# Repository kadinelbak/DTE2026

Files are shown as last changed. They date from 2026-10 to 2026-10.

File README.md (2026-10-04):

# DTE 2026

Hardware for the DTE Designathon project.

## EMG + Stretch Sensor Board

KiCad 8 project in [`hardware/emg_board/`](hardware/emg_board/). Open `emg_board.kicad_pro` in KiCad; the symbol and footprint libraries are project-local, so nothing needs to be installed.

```
hardware/emg_board/
├── emg_board.kicad_pro     project
├── emg_board.kicad_sch     schematic
├── emg_board.kicad_pcb     PCB layout
├── EMG_Board.kicad_sym     project symbol library
├── EMG_Board.pretty/       project footprint library (*.kicad_mod)
├── sym-lib-table           points to ${KIPRJMOD}/EMG_Board.kicad_sym
├── fp-lib-table            points to ${KIPRJMOD}/EMG_Board.pretty
└── docs/                   schematic and PCB previews and screenshots
```

The board runs from a 9 V battery through a switch, a reverse-polarity diode and a 7805 regulator into an ESP32 DevKit (38-pin). It carries:

- an EMG front end (instrumentation amp, 8 Hz high-pass, ~800 Hz low-pass, total gain ~1200) on IO34
- a Wheatstone bridge for two stretch sensors on IO35 / IO33
- a potentiometer on IO32
- three indicator LEDs on IO25 / IO26 / IO27

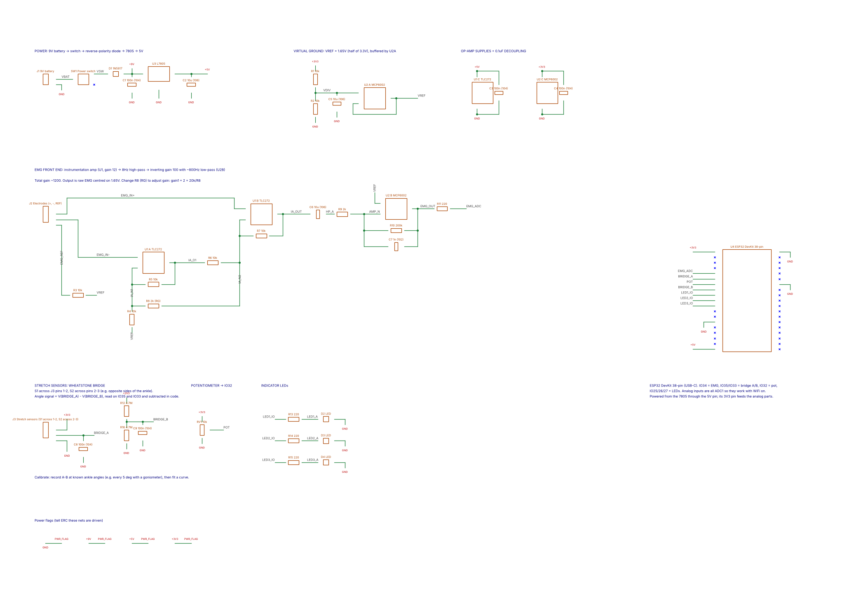
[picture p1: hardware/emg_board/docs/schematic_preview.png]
Schematic

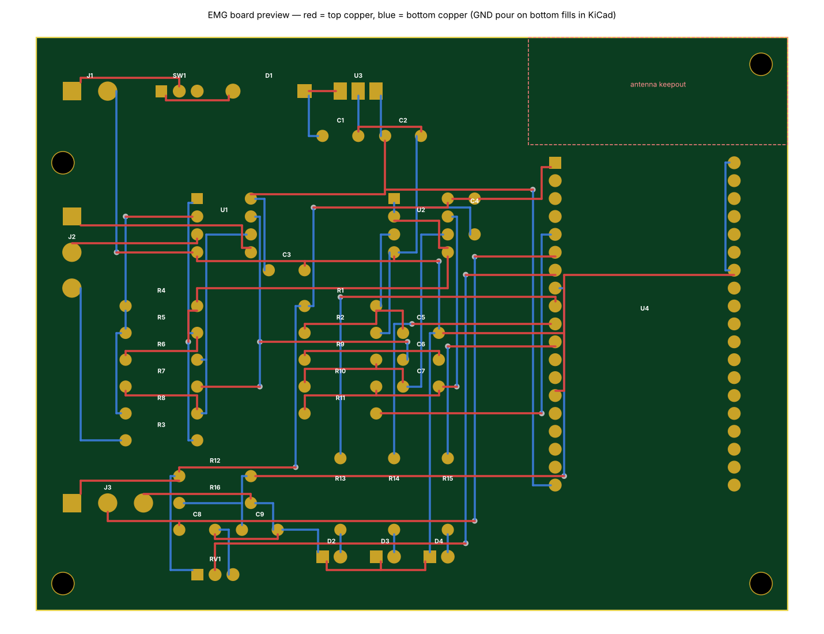
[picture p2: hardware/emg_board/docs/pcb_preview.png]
PCB


### KiCad screenshots

PCB layout:

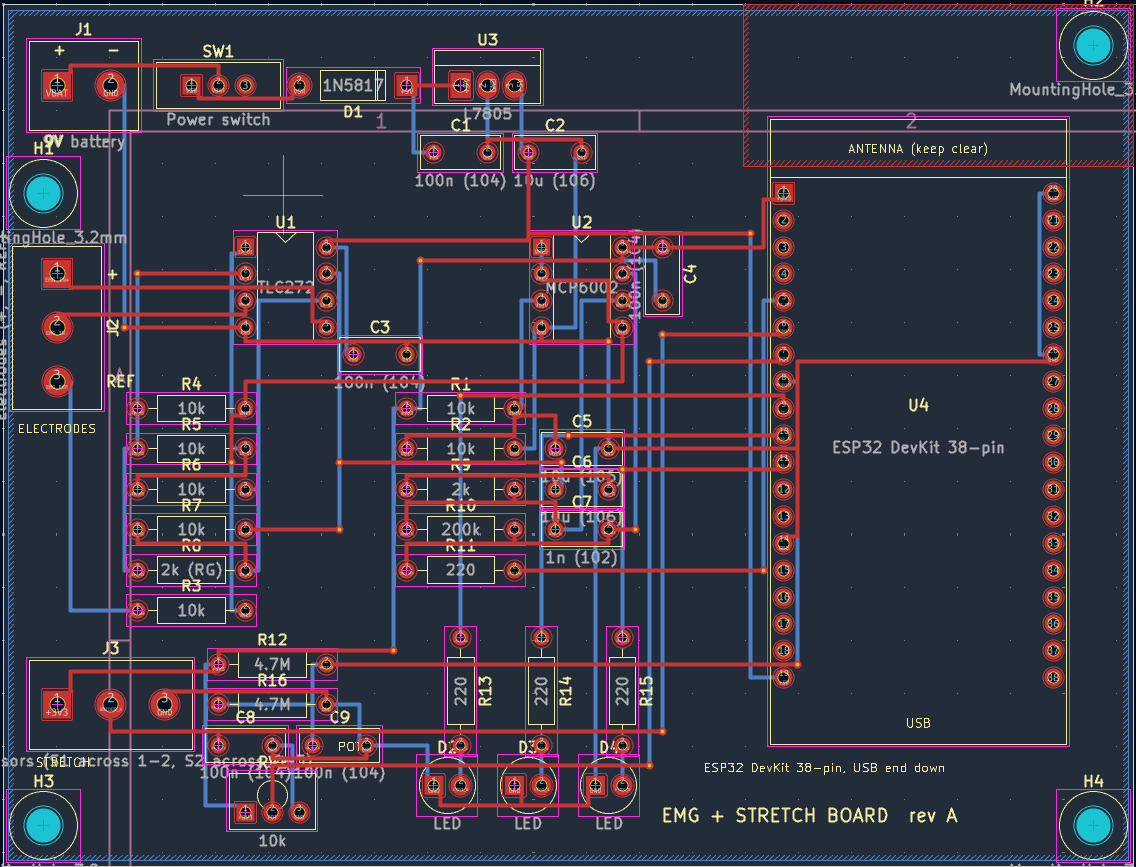
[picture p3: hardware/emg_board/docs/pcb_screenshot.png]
PCB layout in KiCad


Schematic:

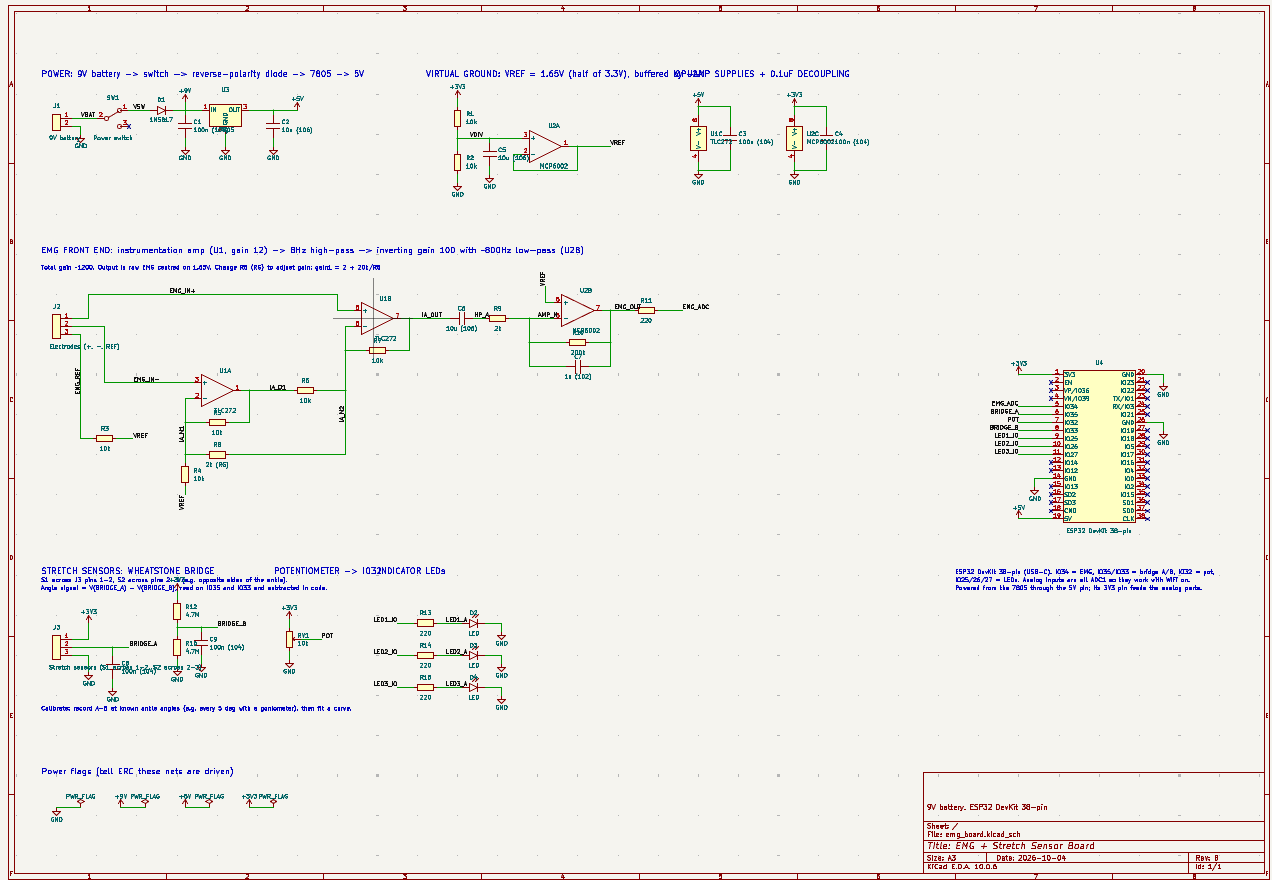
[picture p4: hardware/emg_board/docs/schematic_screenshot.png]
Schematic in KiCad


## Microcontroller code

Arduino sketches in [`microcontroller_code/`](microcontroller_code/). Each sketch is in a folder with the same name, as the Arduino IDE expects.

- [`WiFi/`](microcontroller_code/WiFi/): ESP32 button that sends a "Danger mode approached, increase stiffness?" alert to the phone and Apple Watch through ntfy.sh. The notification has Increase stiffness and Decrease stiffness buttons that change the stiffness level (0 to 5) on the ESP32, which confirms with a follow-up notification. The LEDs show the stiffness level: green for low (0-1), yellow for medium (2-3) and red for high (4-5). Before building, copy `secrets.example.h` to `secrets.h` and put your WiFi name and password in it. `secrets.h` is git-ignored so the password stays out of the repo.
- [`EMG/`](microcontroller_code/EMG/): samples the EMG signal on A0 at 1200 Hz, cancels 60 Hz mains hum with a one-cycle comb filter, and prints the smoothed muscle-activity envelope over serial at 115200 baud.
- [`RotationalDrive/`](microcontroller_code/RotationalDrive/): reads the outside stretch sensor on A1, zeroes at neutral, and lights a blue warning LED and a blinking red danger LED as the ankle rolls past the limits. Type an angle over serial to calibrate it to degrees (saved to EEPROM), or `z` to re-zero.

## CAD

SolidWorks files for the hydraulic right foot brace are in [`cad/hydraulic_brace/`](cad/hydraulic_brace/): the assembly (`hydraulics brace Assem.SLDASM`), the brace body (`hydraulic right foot brace`), `bottom brace`, `BottomBraceHydraulics`, `InnerBore`, `OuterBore` and `Gasket`. Keep the file names as they are, because the assembly finds its parts by name.

## Images

- [`images/model/`](images/model/): SolidWorks render of the full brace assembly.

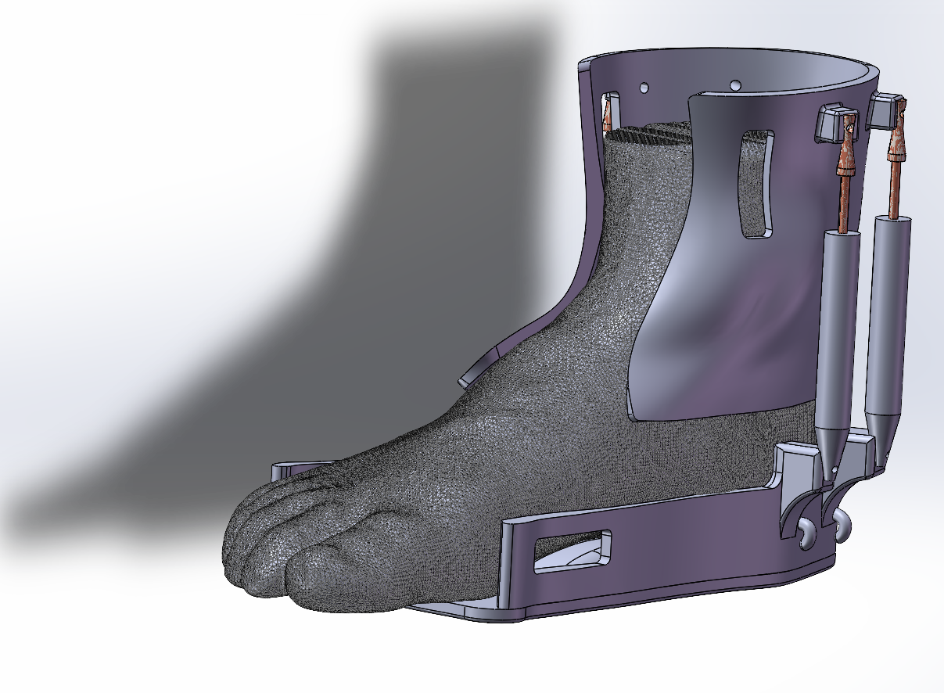
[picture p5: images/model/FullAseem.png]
Brace model


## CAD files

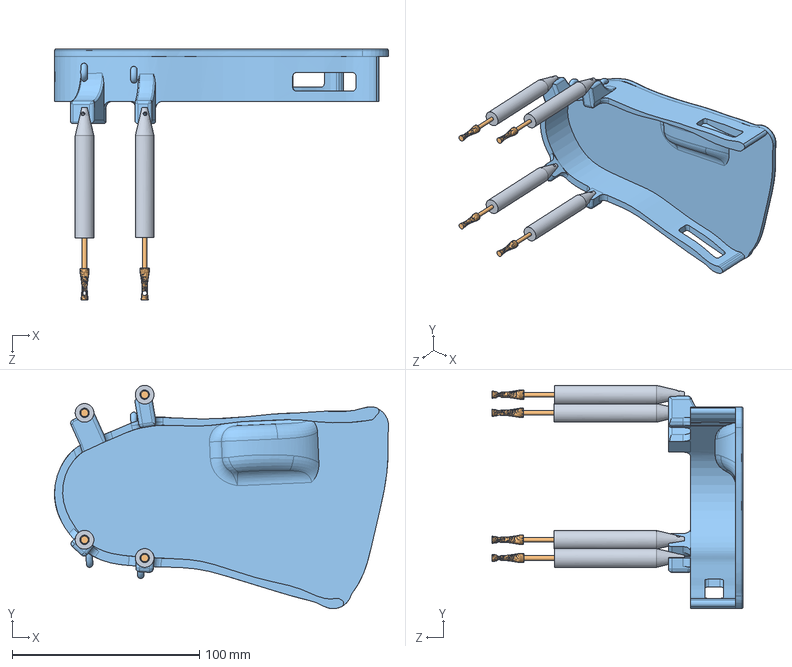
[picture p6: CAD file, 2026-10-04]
cad/hydraulic_brace/hydraulics brace Assem.SLDASM
178.3 x 119.2 x 134.2 mm
BottomBraceHydraulics
InnerBore x 4
OuterBore x 4

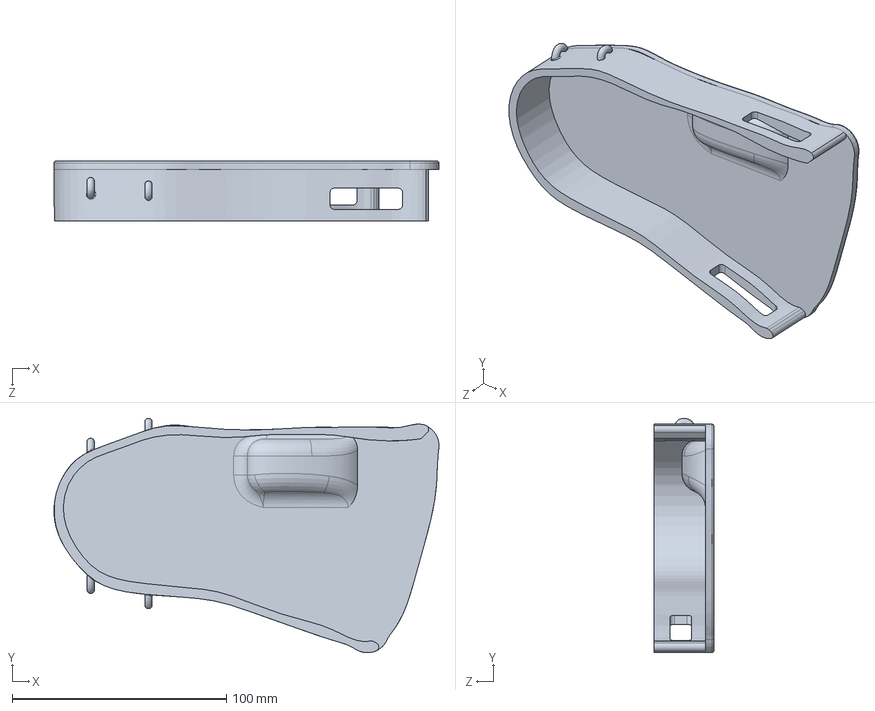
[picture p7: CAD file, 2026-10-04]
cad/hydraulic_brace/bottom brace.SLDPRT
179.8 x 109.5 x 28.0 mm

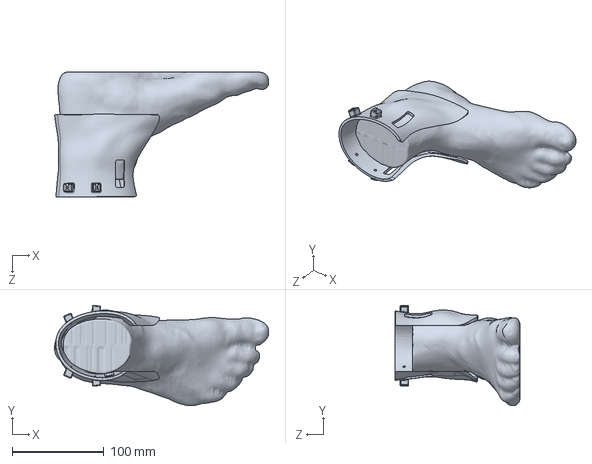
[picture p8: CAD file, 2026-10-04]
cad/hydraulic_brace/hydraulic right foot brace.SLDPRT
232.8 x 109.1 x 136.4 mm

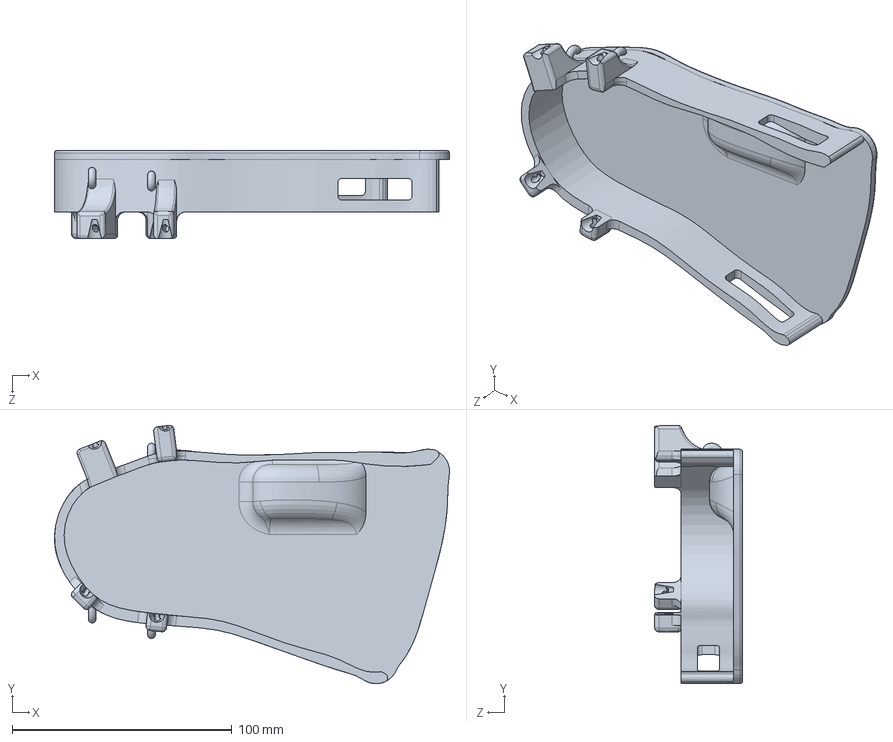
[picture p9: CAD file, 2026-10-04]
cad/hydraulic_brace/BottomBraceHydraulics.SLDPRT
179.8 x 117.7 x 40.0 mm

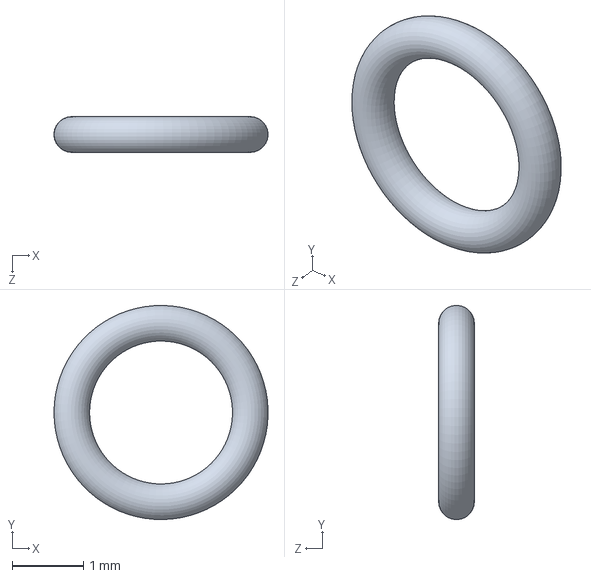
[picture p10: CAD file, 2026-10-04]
cad/hydraulic_brace/Gasket.SLDPRT
3.00 x 3.00 x 0.499 mm

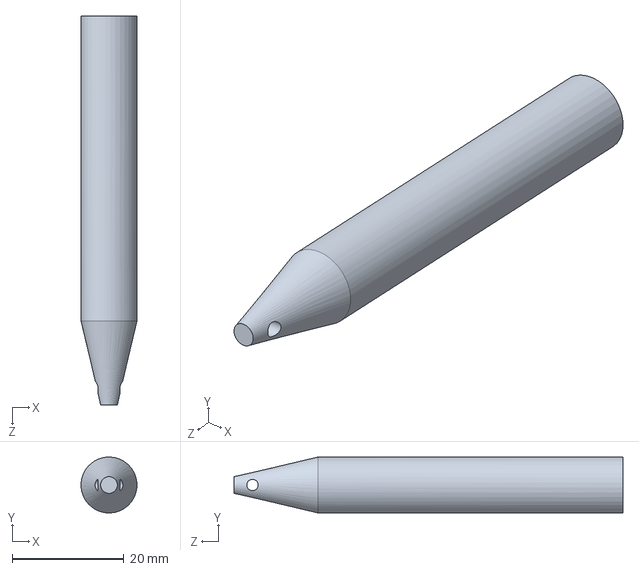
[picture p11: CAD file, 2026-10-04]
cad/hydraulic_brace/OuterBore.SLDPRT
10.0 x 9.99 x 69.5 mm

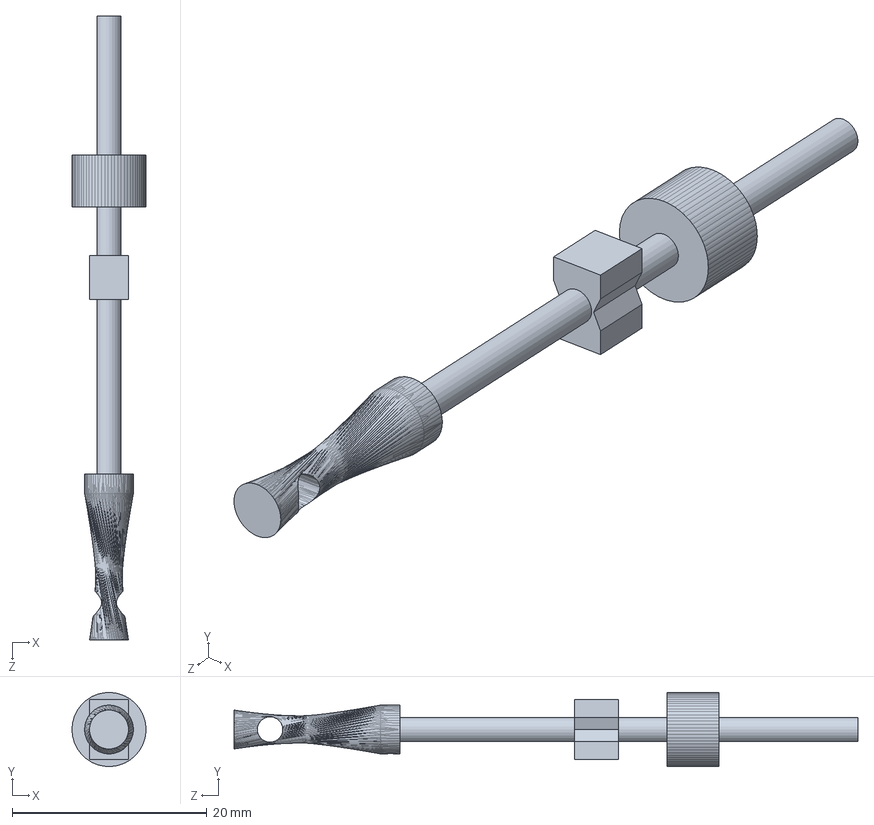
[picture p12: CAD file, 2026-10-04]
cad/hydraulic_brace/InnerBore.SLDPRT
7.60 x 7.59 x 64.0 mm

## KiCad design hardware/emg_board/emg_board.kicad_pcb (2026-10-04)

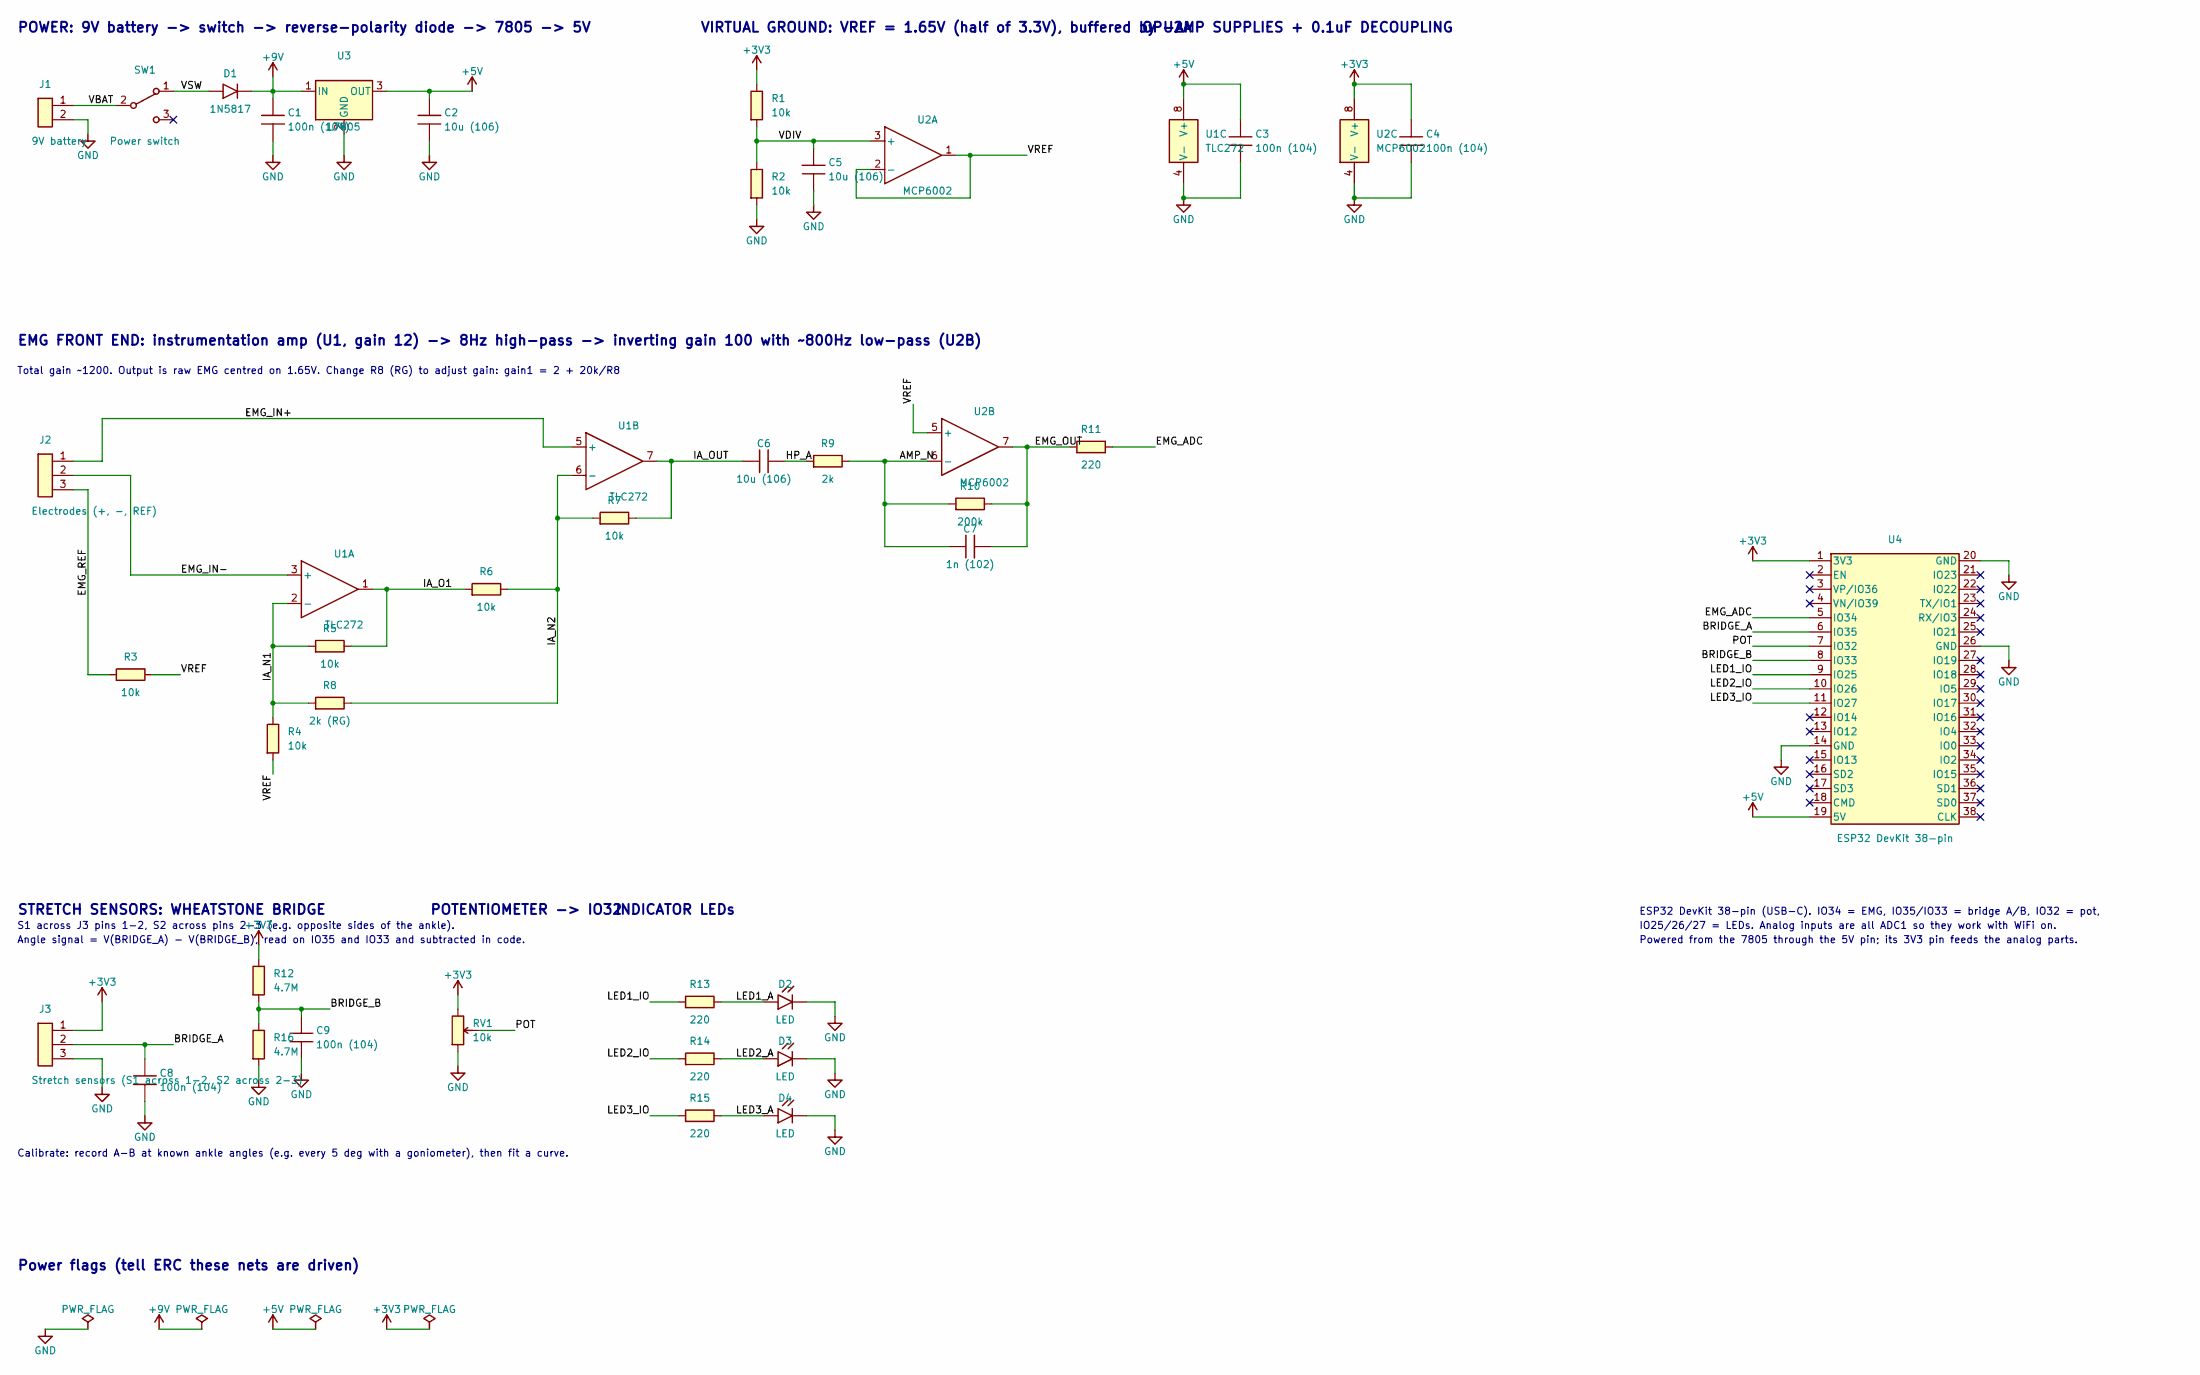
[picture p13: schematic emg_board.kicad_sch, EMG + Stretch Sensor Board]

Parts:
C1, C3, C4, C8, C9: 100n (104); C_Disc_P5.08mm
C2, C5, C6: 10u (106); C_Disc_P5.08mm
C7: 1n (102); C_Disc_P5.08mm
D1: 1N5817; D_DO-41_P10.16mm
D2, D3, D4: LED; LED_D5.0mm
J1: 9V battery; TerminalBlock_1x02_P5.08mm
J2: Electrodes (+, -, REF); TerminalBlock_1x03_P5.08mm
J3: Stretch sensors (S1 across 1-2, S2 across 2-3); TerminalBlock_1x03_P5.08mm
R1, R2, R3, R4, R5, R6, R7: 10k; R_Axial_P10.16mm
R8: 2k (RG); R_Axial_P10.16mm
R9: 2k; R_Axial_P10.16mm
R10: 200k; R_Axial_P10.16mm
R11, R13, R14, R15: 220; R_Axial_P10.16mm
R12, R16: 4.7M; R_Axial_P10.16mm
RV1: 10k; Potentiometer_Inline_P2.54mm
SW1: Power switch; SW_Slide_SPDT_P2.54mm
U1: TLC272; DIP-8_W7.62mm
U2: MCP6002; DIP-8_W7.62mm
U3: L7805; TO-220-3_Vertical
U4: ESP32 DevKit 38-pin; ESP32_DevKitC_38pin_W25.4mm

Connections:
+3V3: C4.1, J3.1, R1.1, R12.1, RV1.1, U2.8 (V+), U4.1 (3V3)
+5V: C2.1, C3.1, U1.8 (V+), U3.3 (OUT), U4.19 (5V)
+9V: C1.1, D1.1 (K), U3.1 (IN)
AMP_N: C7.1, R9.2, R10.1, U2.6 (-)
BRIDGE_A: C8.1, J3.2, U4.6 (IO35)
BRIDGE_B: C9.1, R12.2, R16.1, U4.8 (IO33)
EMG_ADC: R11.2, U4.5 (IO34)
EMG_IN+: J2.1, U1.5 (+)
EMG_IN-: J2.2, U1.3 (+)
EMG_OUT: C7.2, R10.2, R11.1, U2.7
EMG_REF: J2.3, R3.1
GND: C1.2, C2.2, C3.2, C4.2, C5.2, C8.2, C9.2, D2.1 (K), D3.1 (K), D4.1 (K), J1.2, J3.3, R2.2, R16.2, RV1.3, U1.4 (V-), U2.4 (V-), U3.2 (GND), U4.14 (GND), U4.20 (GND), U4.26 (GND)
HP_A: C6.2, R9.1
IA_N1: R4.1, R5.1, R8.1, U1.2 (-)
IA_N2: R6.2, R7.1, R8.2, U1.6 (-)
IA_O1: R5.2, R6.1, U1.1
IA_OUT: C6.1, R7.2, U1.7
LED1_A: D2.2 (A), R13.2
LED1_IO: R13.1, U4.9 (IO25)
LED2_A: D3.2 (A), R14.2
LED2_IO: R14.1, U4.10 (IO26)
LED3_A: D4.2 (A), R15.2
LED3_IO: R15.1, U4.11 (IO27)
POT: RV1.2, U4.7 (IO32)
VBAT: J1.1, SW1.2 (B)
VDIV: C5.1, R1.2, R2.1, U2.3 (+)
VREF: R3.2, R4.2, U2.1, U2.2 (-), U2.5 (+)
VSW: D1.2 (A), SW1.1 (A)

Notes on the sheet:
POWER: 9V battery -> switch -> reverse-polarity diode -> 7805 -> 5V
VIRTUAL GROUND: VREF = 1.65V (half of 3.3V), buffered by U2A
OP-AMP SUPPLIES + 0.1uF DECOUPLING
EMG FRONT END: instrumentation amp (U1, gain 12) -> 8Hz high-pass -> inverting gain 100 with ~800Hz low-pass (U2B)
Total gain ~1200. Output is raw EMG centred on 1.65V. Change R8 (RG) to adjust gain: gain1 = 2 + 20k/R8
STRETCH SENSORS: WHEATSTONE BRIDGE
S1 across J3 pins 1-2, S2 across pins 2-3 (e.g. opposite sides of the ankle).
Angle signal = V(BRIDGE_A) - V(BRIDGE_B), read on IO35 and IO33 and subtracted in code.
Calibrate: record A-B at known ankle angles (e.g. every 5 deg with a goniometer), then fit a curve.
POTENTIOMETER -> IO32
INDICATOR LEDs
ESP32 DevKit 38-pin (USB-C). IO34 = EMG, IO35/IO33 = bridge A/B, IO32 = pot,
IO25/26/27 = LEDs. Analog inputs are all ADC1 so they work with WiFi on.
Powered from the 7805 through the 5V pin; its 3V3 pin feeds the analog parts.
Power flags (tell ERC these nets are driven)

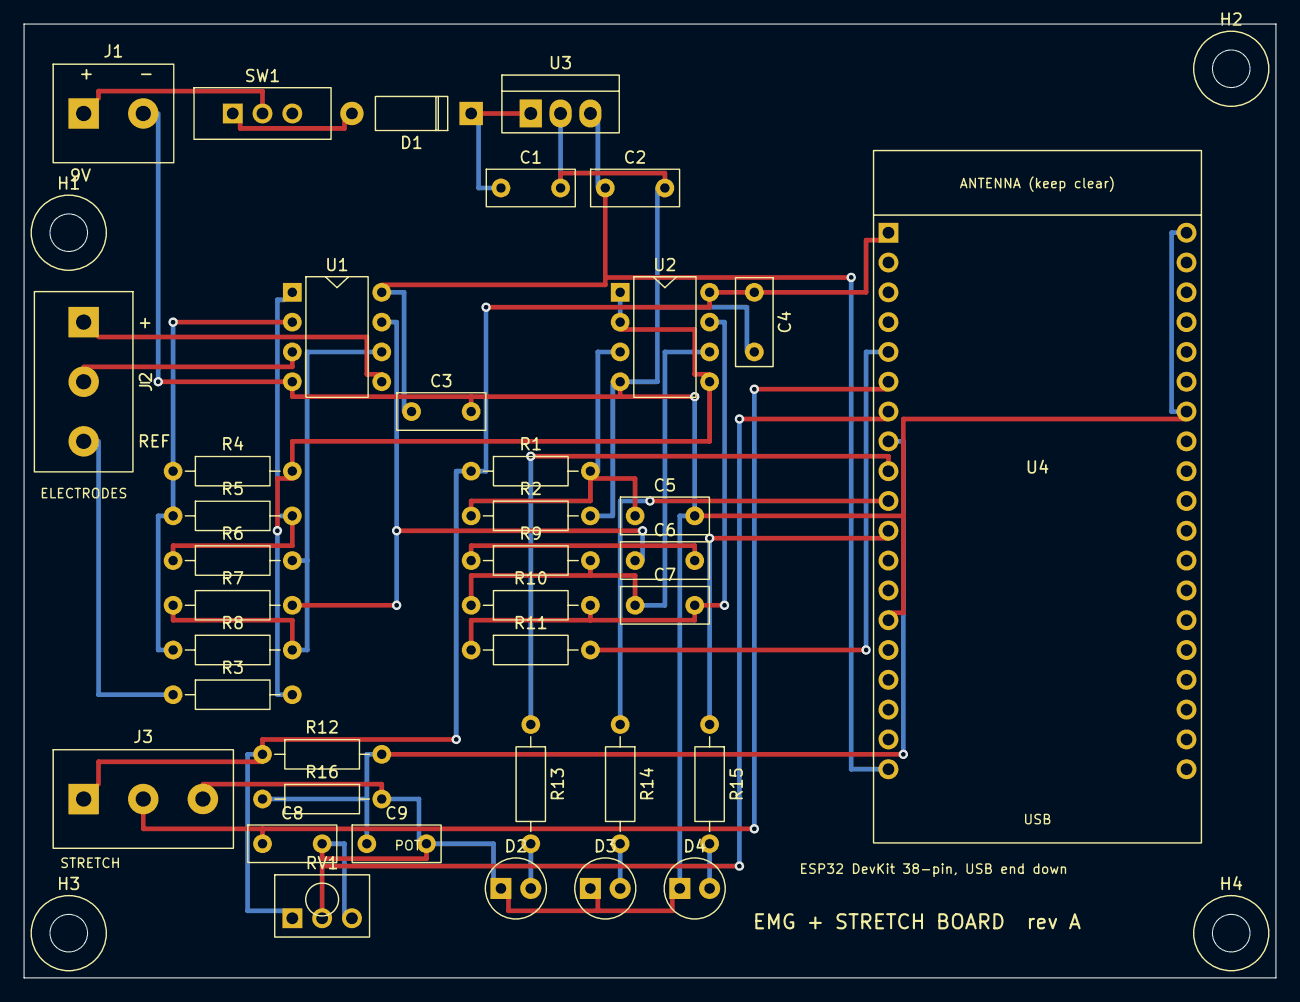
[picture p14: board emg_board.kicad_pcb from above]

Board: 2 copper layers, 106.7 x 81.3 mm, 42 parts (0 on the bottom side), 28 nets.

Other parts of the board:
H1, H2, H3, H4: MountingHole_3.2mm

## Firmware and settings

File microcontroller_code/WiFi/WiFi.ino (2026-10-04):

/*
  ESP32 button -> Apple Watch "danger mode" alert with stiffness control
  ----------------------------------------------------------------------
  Press the button and your Apple Watch buzzes with "Danger mode approached"
  and asks whether to increase stiffness. The notification has two buttons,
  "Increase stiffness" and "Decrease stiffness", which send a command back to
  the ESP32 and change the stiffness level (0 to MAX_STIFFNESS).
  Uses ntfy.sh (free, no account) over WiFi: install the "ntfy" app on your
  iPhone and subscribe to NTFY_TOPIC. iPhone notifications mirror to the Watch.

  LEDs show the stiffness level (one LED stays on):
    Green  (OK_LED)      = low stiffness     (level 0-1)
    Yellow (STATUS_LED)  = medium stiffness  (level 2-3)
    Red    (ERR_LED)     = high stiffness    (level 4-5)
  Other LED signals:
    Yellow blinking      = connecting to WiFi, solid while sending
    New level's LED      flashes 3x when the stiffness changes
    Red flashes 3x       = send failed (check WiFi / topic)
    Current LED flashes 1x when stiffness is already at max / min

  Wiring (resistors are 220-330 ohm):
    Button:      one leg -> GPIO 13, other leg -> GND   (internal pull-up, no resistor needed)
    Yellow LED:  GPIO 25 -> resistor -> LED long leg; LED short leg -> GND
    Green LED:   GPIO 26 -> resistor -> LED long leg; LED short leg -> GND
    Red LED:     GPIO 27 -> resistor -> LED long leg; LED short leg -> GND

  Board:   any ESP32 (Tools > Board > esp32 > "ESP32 Dev Module")
  Library: all built into the ESP32 Arduino core
*/

#include <WiFi.h>
#include <HTTPClient.h>
#include <WiFiClientSecure.h>

// ---- Change these ----
#include "secrets.h"   // WIFI_SSID and WIFI_PASS (copy secrets.example.h to secrets.h)
const char *NTFY_TOPIC = "dte-esp32-change-me-8f3k2";      // ESP32 -> phone. Make it random; anyone who knows it can read it
const char *NTFY_CMD_TOPIC = "dte-esp32-change-me-8f3k2-cmd";  // phone -> ESP32
 
#define BUTTON_PIN  13
#define STATUS_LED  25
#define OK_LED      26
#define ERR_LED     27
 
#define DEBOUNCE_MS 50
#define COOLDOWN_MS 2000   // ignore presses for 2 s after sending (ntfy rate-limits spam)
#define POLL_MS     3000   // how often to check for commands from the phone
#define MAX_STIFFNESS 5    // stiffness levels go from 0 (softest) to this
#define START_STIFFNESS 2
 
int pressCount = 0;
int stiffness = START_STIFFNESS;
int lastReading = HIGH;
int buttonState = HIGH;
unsigned long lastChange = 0;
unsigned long lastSent = 0;
unsigned long lastPoll = 0;
String lastCmdId = "";     // id of the last command handled, so each runs once
 
void flash(int pin, int times, int ms) {
  int before = digitalRead(pin);   // restore afterwards, so a phone-set "on" stays on
  for (int i = 0; i < times; i++) {
    digitalWrite(pin, HIGH); delay(ms);
    digitalWrite(pin, LOW);  delay(ms);
  }
  digitalWrite(pin, before);
}
 
void listNetworks() {
  // Prints every WiFi network the ESP32 can see. If yours isn't listed, it's
  // probably 5 GHz only (ESP32 needs 2.4 GHz) or out of range.
  Serial.println("Networks the ESP32 can see:");
  int n = WiFi.scanNetworks();
  for (int i = 0; i < n; i++) {
    Serial.printf("  \"%s\"  signal %d dBm  %s\n", WiFi.SSID(i).c_str(), WiFi.RSSI(i),
                  WiFi.encryptionType(i) == WIFI_AUTH_WPA2_ENTERPRISE ? "(enterprise login, won't work)" : "");
  }
  if (n == 0) Serial.println("  (none found)");
  WiFi.scanDelete();
}
 
bool wifiStarted = false;
 
void connectWiFi() {
  if (WiFi.status() == WL_CONNECTED) return;
 
  if (!wifiStarted) {
    Serial.printf("Connecting to WiFi \"%s\"", WIFI_SSID);
    WiFi.mode(WIFI_STA);
    WiFi.setAutoReconnect(true);
    WiFi.setSleep(false);               // phone hotspots often drop ESP32s that use WiFi power-saving
    WiFi.begin(WIFI_SSID, WIFI_PASS);   // only called once; calling it again mid-attempt causes "sta is connecting"
    wifiStarted = true;
  } else {
    Serial.print("WiFi dropped, reconnecting");
    WiFi.reconnect();
  }
 
  unsigned long start = millis();
  while (WiFi.status() != WL_CONNECTED && millis() - start < 15000) {
    digitalWrite(STATUS_LED, !digitalRead(STATUS_LED));   // blink while connecting
    delay(250);
    Serial.print(".");
  }
  digitalWrite(STATUS_LED, LOW);
  if (WiFi.status() == WL_CONNECTED) {
    Serial.print(" connected, IP ");
    Serial.println(WiFi.localIP());
  } else {
    // 1 = network not found, 4 = connect failed (usually wrong password), 6 = disconnected
    Serial.printf(" FAILED (status %d)\n", WiFi.status());
    WiFi.disconnect();   // stop trying so the scan below can run
    delay(200);
    listNetworks();
  }
}
 
// Which LED shows the current stiffness: green = low, yellow = medium, red = high.
int stiffnessLed() {
  if (stiffness <= 1) return OK_LED;
  if (stiffness <= 3) return STATUS_LED;
  return ERR_LED;
}

// Turns on only the LED for the current stiffness.
void showStiffness() {
  digitalWrite(OK_LED, LOW);
  digitalWrite(STATUS_LED, LOW);
  digitalWrite(ERR_LED, LOW);
  digitalWrite(stiffnessLed(), HIGH);
}

// Sets a new stiffness level and shows it on the LEDs.
// This is where the damper / actuator output goes once it is wired up
// (e.g. set the MR coil PWM duty from the level).
void setStiffness(int level) {
  stiffness = level;
  Serial.printf("Stiffness now %d/%d\n", stiffness, MAX_STIFFNESS);
  showStiffness();
  flash(stiffnessLed(), 3, 150);   // flash the new colour so the change is obvious
}

// Sends a notification. withStiffnessButtons adds the increase / decrease buttons.
bool sendNotification(const String &title, const String &message,
                      const char *priority, const char *tags, bool withStiffnessButtons) {
  connectWiFi();
  if (WiFi.status() != WL_CONNECTED) return false;
 
  digitalWrite(STATUS_LED, HIGH);
  WiFiClientSecure client;
  client.setInsecure();               // skips certificate check; fine for a prototype
  HTTPClient http;
  http.begin(client, String("https://ntfy.sh/") + NTFY_TOPIC);
  http.addHeader("Title", title);
  http.addHeader("Priority", priority);  // "urgent"/"high" give a stronger buzz on the watch
  http.addHeader("Tags", tags);          // shows an emoji on the notification
  if (withStiffnessButtons) {
    // Buttons on the notification that send a command back to the ESP32.
    String cmdUrl = String("https://ntfy.sh/") + NTFY_CMD_TOPIC;
    http.addHeader("Actions", "http, Increase stiffness, " + cmdUrl + ", body=up, clear=true; "
                              "http, Decrease stiffness, " + cmdUrl + ", body=down, clear=true");
  }
  int code = http.POST(message);
  http.end();
  digitalWrite(STATUS_LED, LOW);
 
  Serial.printf("ntfy -> HTTP %d\n", code);
  return code == 200;
}
 
// Pulls the value of "key":"..." out of one line of ntfy's JSON.
String jsonField(const String &line, const String &key) {
  String tag = "\"" + key + "\":\"";
  int start = line.indexOf(tag);
  if (start < 0) return "";
  start += tag.length();
  int end = line.indexOf('"', start);
  return end < 0 ? "" : line.substring(start, end);
}
 
void handleCommand(String cmd) {
  cmd.trim();
  cmd.toLowerCase();
  Serial.printf("Command from phone: \"%s\"\n", cmd.c_str());
 
  if (cmd == "up" || cmd == "down") {
    int target = stiffness + (cmd == "up" ? 1 : -1);
    if (target < 0 || target > MAX_STIFFNESS) {
      flash(stiffnessLed(), 1, 300);
      sendNotification("Stiffness unchanged",
                       String("Already at ") + (target < 0 ? "minimum" : "maximum") +
                       " (" + stiffness + "/" + MAX_STIFFNESS + ")",
                       "default", "warning", true);
      showStiffness();
      return;
    }
    setStiffness(target);
    sendNotification(cmd == "up" ? "Stiffness increased" : "Stiffness decreased",
                     String("Stiffness now ") + stiffness + "/" + MAX_STIFFNESS,
                     "default", cmd == "up" ? "arrow_up" : "arrow_down", true);
    showStiffness();   // sending blinks the yellow LED, so put the stiffness colour back
  }
}
 
// Asks ntfy for any new messages on the command topic.
void pollCommands() {
  if (WiFi.status() != WL_CONNECTED) return;
 
  WiFiClientSecure client;
  client.setInsecure();
  HTTPClient http;
  String since = lastCmdId.length() ? lastCmdId : "10s";
  http.begin(client, String("https://ntfy.sh/") + NTFY_CMD_TOPIC + "/json?poll=1&since=" + since);
  int code = http.GET();
  String body = code == 200 ? http.getString() : "";
  http.end();
  if (code != 200) return;
 
  // One JSON object per line, oldest first.
  int pos = 0;
  while (pos < (int)body.length()) {
    int nl = body.indexOf('\n', pos);
    if (nl < 0) nl = body.length();
    String line = body.substring(pos, nl);
    pos = nl + 1;
 
    if (jsonField(line, "event") != "message") continue;
    String id = jsonField(line, "id");
    if (id.length() == 0 || id == lastCmdId) continue;
    lastCmdId = id;
    handleCommand(jsonField(line, "message"));
  }
}
 
void setup() {
  Serial.begin(115200);
  pinMode(BUTTON_PIN, INPUT_PULLUP);   // reads LOW when pressed
  pinMode(STATUS_LED, OUTPUT);
  pinMode(OK_LED, OUTPUT);
  pinMode(ERR_LED, OUTPUT);
 
  // Quick LED self-test so you know all three are wired right.
  flash(STATUS_LED, 1, 150); flash(OK_LED, 1, 150); flash(ERR_LED, 1, 150);
 
  connectWiFi();
  if (WiFi.status() == WL_CONNECTED) flash(OK_LED, 2, 100);
  else flash(ERR_LED, 3, 150);
  showStiffness();
}
 
void loop() {
  int reading = digitalRead(BUTTON_PIN);
  if (reading != lastReading) lastChange = millis();
  lastReading = reading;
 
  if (millis() - lastChange > DEBOUNCE_MS && reading != buttonState) {
    buttonState = reading;
 
    if (buttonState == LOW && millis() - lastSent > COOLDOWN_MS) {   // just pressed
      pressCount++;
      lastSent = millis();
      Serial.printf("Button pressed (#%d), sending...\n", pressCount);
 
      String msg = String("Danger mode approached. Increase stiffness? (now ") +
                   stiffness + "/" + MAX_STIFFNESS + ")";
      if (sendNotification("Danger mode approached", msg, "urgent", "warning", true)) {
        flash(stiffnessLed(), 1, 400);
      } else {
        flash(ERR_LED, 3, 150);
      }
      showStiffness();
    }
  }
 
  // Check for commands from the phone every few seconds.
  // (Each check takes about half a second, so a very quick button tap during one may be missed.)
  if (millis() - lastPoll > POLL_MS) {
    lastPoll = millis();
    pollCommands();
  }
}

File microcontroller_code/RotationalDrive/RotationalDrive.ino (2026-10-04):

#include <EEPROM.h>

// ---------- pins ----------
const int SENSOR_PIN = A1;     // outside stretch sensor
const int LED_BLUE   = 8;      // warning
const int LED_RED    = 9;      // too far

// ---------- circuit ----------
const float VCC     = 5.0;
const float R_FIXED = 4000000.0;   // fixed resistor on A1, in ohms: set to yours
const unsigned long SAMPLE_MS = 500;

// ---------- warning limits ----------
// Used once you've calibrated to degrees:
const float WARN_DEG   = 15.0;     // blue on above this
const float DANGER_DEG = 25.0;     // red on above this
// Used before calibration (percent change from neutral):
const float WARN_PCT   = 10.0;
const float DANGER_PCT = 20.0;
const float HYSTERESIS = 0.1;      // must drop 10% below a limit to switch off (stops flicker)

float baseV = 0, degPerPct = 0, smoothV = 0;
int level = 0;                      // 0 ok, 1 warning, 2 danger

float readVolts() {
  analogRead(SENSOR_PIN);
  delayMicroseconds(200);
  long sum = 0;
  for (int i = 0; i < 20; i++) sum += analogRead(SENSOR_PIN);
  return (sum / 20.0) * VCC / 1023.0;
}

float pctChange(float v) { return (v - baseV) / baseV * 100.0; }

// Stretch sensor resistance from the A1 voltage (sensor is the bottom half of the divider)
float sensorR(float v) {
  if (v < 0.005 || v > VCC - 0.005) return -1;   // -1 = out of range (shorted or open)
  return R_FIXED * v / (VCC - v);
}

// Picks the warning level from a value and its two limits, with hysteresis
int checkLevel(float value, float warn, float danger) {
  value = fabs(value);                         // too far in either direction counts
  if (value > danger) return 2;
  if (level == 2 && value > danger * (1 - HYSTERESIS)) return 2;
  if (value > warn) return 1;
  if (level >= 1 && value > warn * (1 - HYSTERESIS)) return 1;
  return 0;
}

void setup() {
  Serial.begin(115200);
  pinMode(LED_BLUE, OUTPUT);
  pinMode(LED_RED, OUTPUT);

  // LED test: each lights briefly so you know they're wired right
  digitalWrite(LED_BLUE, HIGH); delay(300); digitalWrite(LED_BLUE, LOW);
  digitalWrite(LED_RED,  HIGH); delay(300); digitalWrite(LED_RED,  LOW);

  EEPROM.get(0, degPerPct);
  if (isnan(degPerPct) || degPerPct == 0 || fabs(degPerPct) > 1000) degPerPct = 0;

  Serial.println("Hold ankle in neutral, zeroing in 3 s...");
  digitalWrite(LED_BLUE, HIGH);                // blue on while zeroing
  delay(3000);
  baseV = readVolts();
  smoothV = baseV;
  digitalWrite(LED_BLUE, LOW);

  Serial.print("Resting sensor resistance: ");
  Serial.print(sensorR(baseV), 0);
  Serial.println(" ohms");

  Serial.println("Commands: z = re-zero (ankle neutral), or type an angle you're holding, e.g. 20");
  if (degPerPct == 0) Serial.println("Not calibrated: warnings use % change until you calibrate.");
}

void loop() {
  // --- commands ---
  if (Serial.available()) {
    String cmd = Serial.readStringUntil('\n');
    cmd.trim();
    if (cmd == "z") {
      baseV = readVolts(); smoothV = baseV;
      Serial.print(">> Zeroed. Resting resistance: ");
      Serial.print(sensorR(baseV), 0);
      Serial.println(" ohms");
    } else if (cmd.length() > 0) {
      float deg = cmd.toFloat();
      float p = pctChange(smoothV);
      if (deg != 0 && fabs(p) > 0.2) {
        degPerPct = deg / p;
        EEPROM.put(0, degPerPct);
        Serial.print(">> Calibrated: "); Serial.print(degPerPct, 3); Serial.println(" deg per 1% (saved).");
      } else {
        Serial.println(">> Not enough change from neutral; roll further and try again.");
      }
    }
  }

  // --- reading ---
  smoothV = 0.7 * smoothV + 0.3 * readVolts();
  float p = pctChange(smoothV);
  float angle = p * degPerPct;

  // --- warning level ---
  if (degPerPct != 0) level = checkLevel(angle, WARN_DEG, DANGER_DEG);
  else                level = checkLevel(p, WARN_PCT, DANGER_PCT);

  static bool blink = false;
  blink = !blink;
  digitalWrite(LED_BLUE, level == 1);
  digitalWrite(LED_RED,  level == 2 && blink);   // red blinks when too far

  // --- print ---
  float r = sensorR(smoothV);
  float r0 = sensorR(baseV);
  Serial.print("V: ");        Serial.print(smoothV, 3);
  Serial.print("  R: ");
  if (r < 0) Serial.print("out of range");
  else {
    Serial.print(r, 0); Serial.print(" ohms");
    if (r0 > 0) {                                  // resistance change from rest
      Serial.print(" (");
      Serial.print((r - r0) / r0 * 100.0, 1);
      Serial.print("%)");
    }
  }
  Serial.print("  change: "); Serial.print(p, 2); Serial.print("%");
  if (degPerPct != 0) { Serial.print("  angle: "); Serial.print(angle, 1); Serial.print(" deg"); }
  Serial.print("  ");
  Serial.println(level == 2 ? "DANGER" : level == 1 ? "warning" : "ok");

  delay(SAMPLE_MS);
}

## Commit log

2026-10-04 Organize KiCad project into hardware/emg_board
    Move footprints into EMG_Board.pretty so fp-lib-table resolves, group
    project files in one folder, drop per-user .kicad_prl, add KiCad
    .gitignore and README.
    Claude-Session: https://claude.ai/code/session_01JBbR2e4UzptNb3MMjR86ub
    [emg_board.kicad_pcb, emg_board.kicad_sch]
2026-10-04 Add KiCad PCB and schematic screenshots
    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
2026-10-04 Add SolidWorks files for the hydraulic right foot brace
    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
    [BottomBraceHydraulics.SLDPRT, Gasket.SLDPRT, InnerBore.SLDPRT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]
2026-10-04 WiFi sketch: danger-mode alert with stiffness up/down buttons
    Button press now sends 'Danger mode approached. Increase stiffness?' with
    Increase/Decrease stiffness ntfy actions; the ESP32 tracks a 0-5 level.
    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
    [WiFi.ino]
2026-10-04 Update hydraulic brace CAD: add SLDASM assembly and bottom brace
    Replaces the .ASM with hydraulics brace Assem.SLDASM and updates the
    brace body, BottomBraceHydraulics and Gasket parts.
    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
    [BottomBraceHydraulics.SLDPRT, Gasket.SLDPRT, bottom brace.SLDPRT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]
2026-10-04 WiFi sketch: LEDs show stiffness level, drop LED on/off commands
    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
    [WiFi.ino]
2026-10-04 Add brace model render and prototype photos
    Prototype photos re-saved without EXIF/GPS metadata.
    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
2026-10-04 EMG sketch: 60 Hz notch and envelope output
    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
2026-10-04 Remove prototype photos to keep the repo zip under 35 MB
    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
